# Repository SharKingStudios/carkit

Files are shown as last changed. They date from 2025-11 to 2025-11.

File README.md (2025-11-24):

<p align="center">
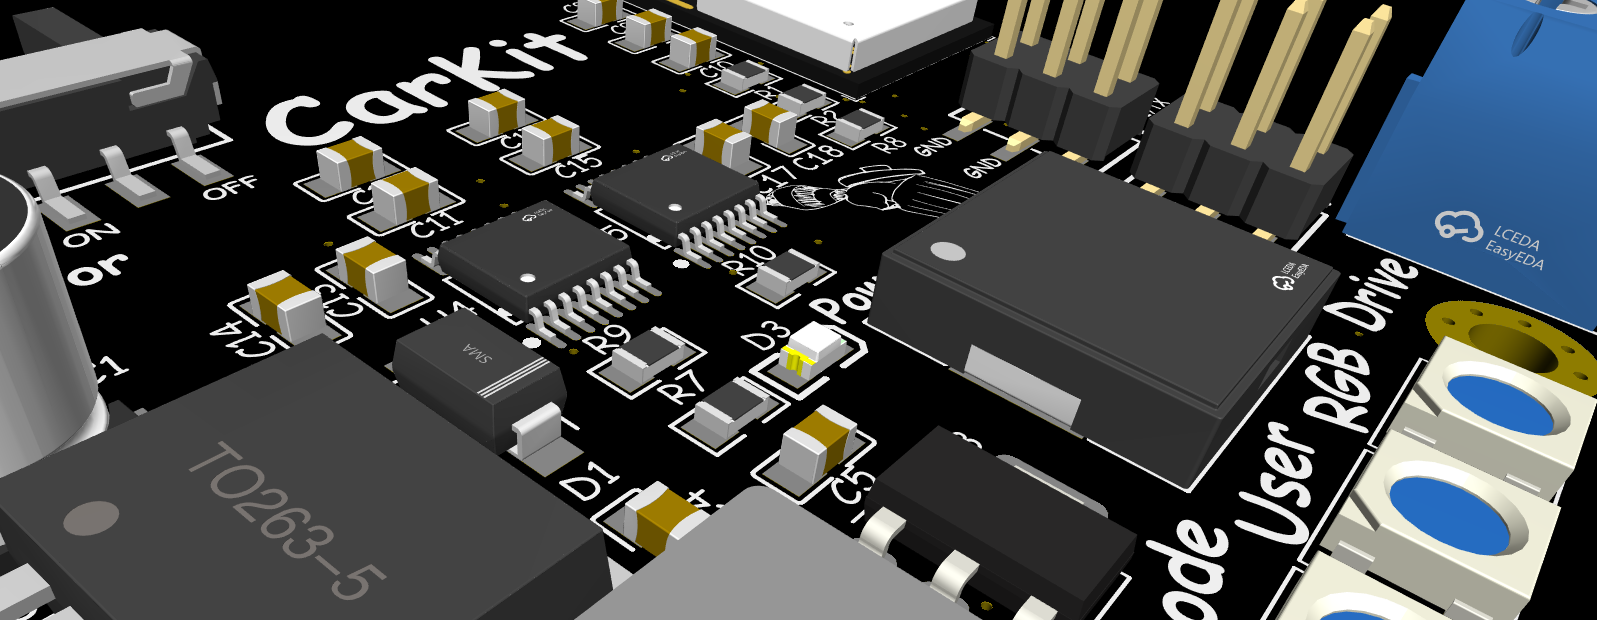
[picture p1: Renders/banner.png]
Banner
  
</p>

# CarKit – Because Your RC Car Needs a Brain  

### A Swiss-Army-Knife Control Board for DIY RC Chaos™  

*(You bring the chassis. It brings the brains.)*  

---

## Renders
*Visuals because everyone loves eye candy.*

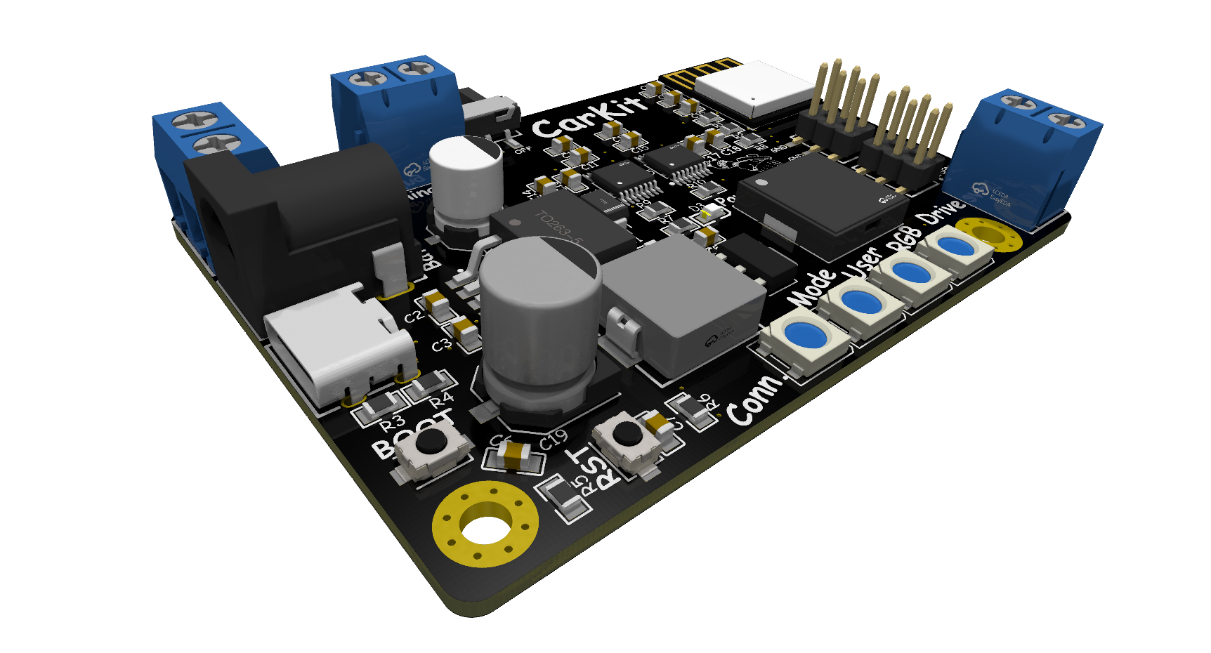
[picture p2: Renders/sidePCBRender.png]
Side PCB Render

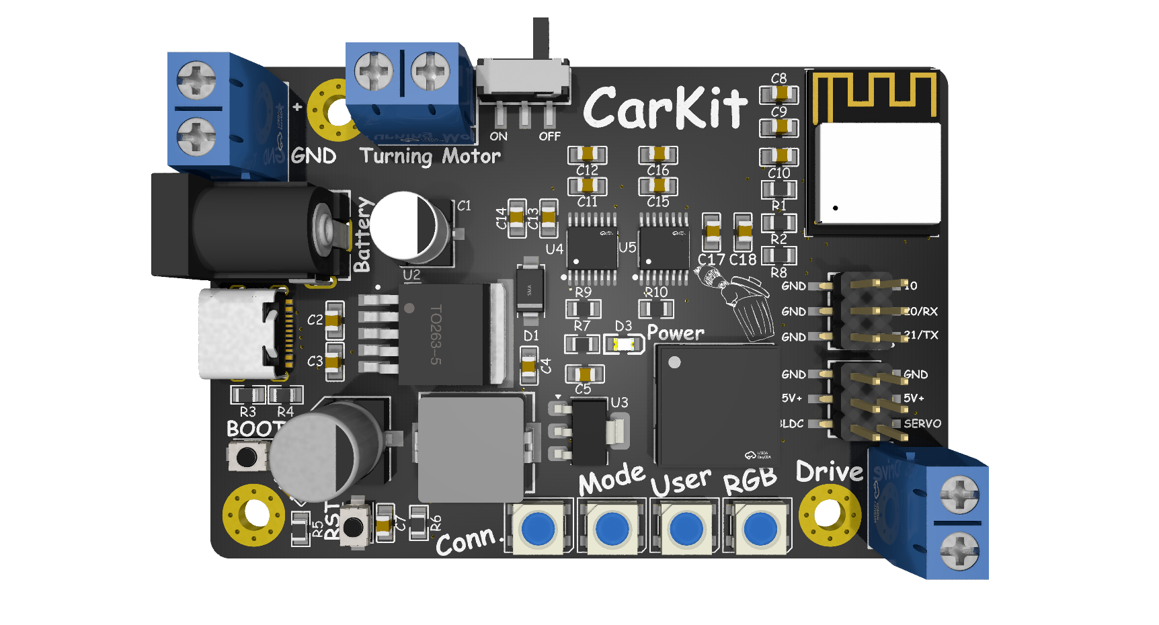
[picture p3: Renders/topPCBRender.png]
Top PCB Render

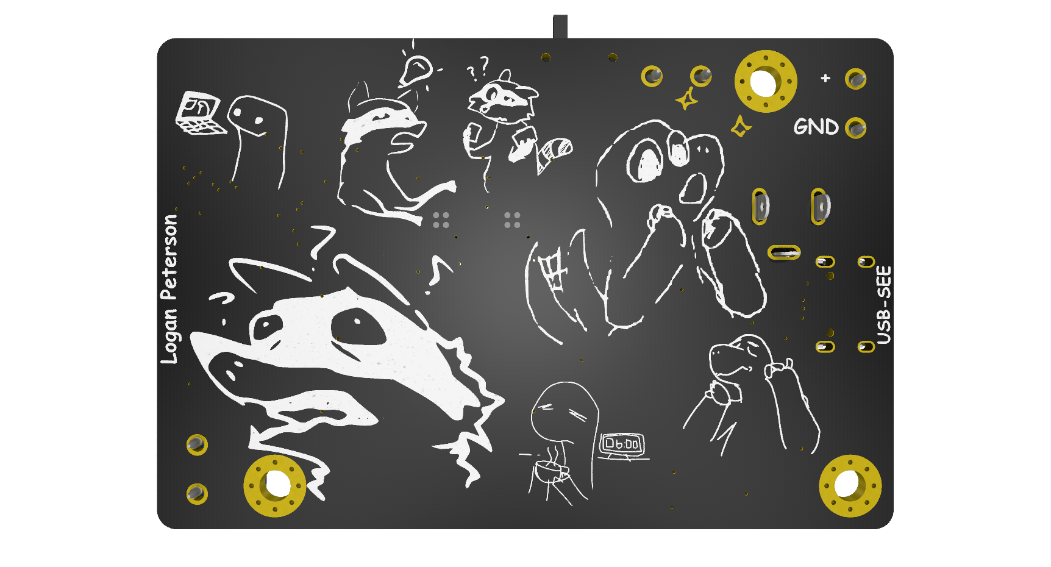
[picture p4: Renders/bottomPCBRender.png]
Bottom PCB Render

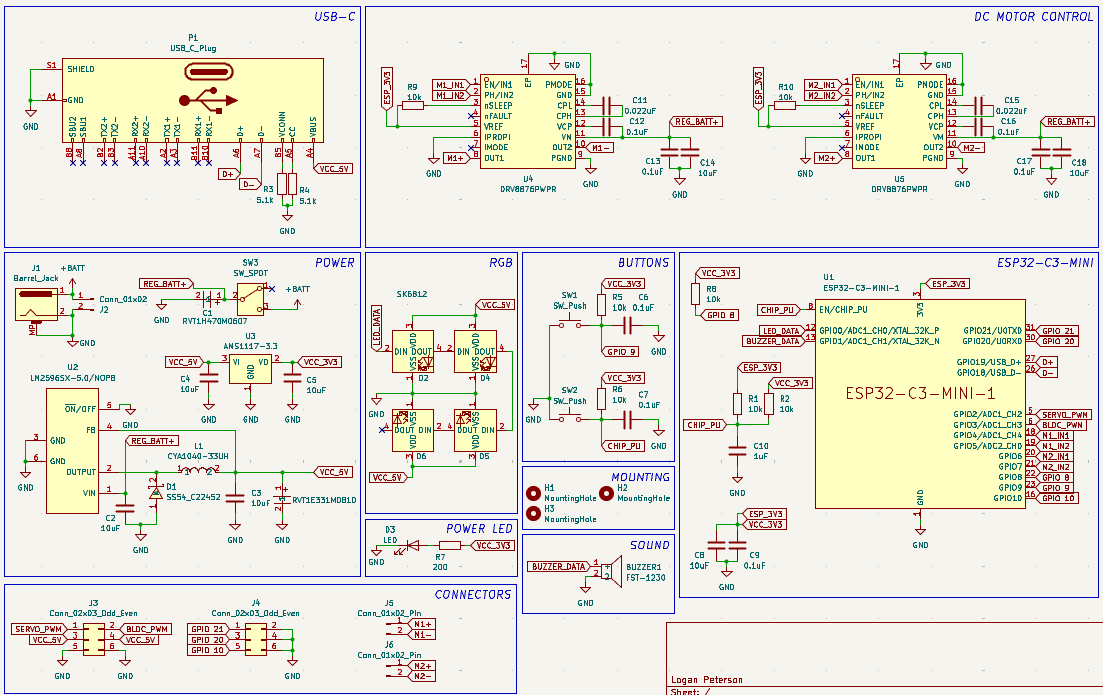
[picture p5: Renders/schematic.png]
Schematic Picture

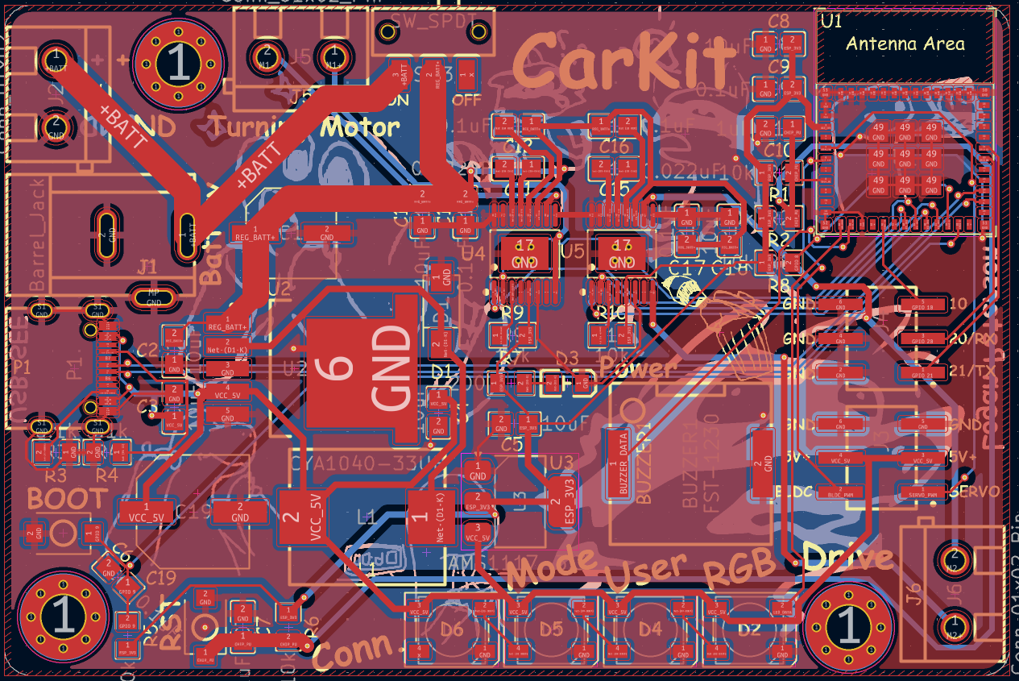
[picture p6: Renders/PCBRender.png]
Routing Glamour Shot


---

## BOM
All the silicon, blinkenlights, and screw-down bits live **[here](/BOM.csv)**.

**Main characters:**
- **MCU:** ESP32-C3-WROOM-02
- **Motor Driver:** DRV8876 dual DC motor driver
- **5 V Regulator:** LM2596SX-5.0 buck converter
- **3.3 V Regulator:** AMS1117-3.3 LDO
- **RGB LEDs:** SK6812 addressable LEDs (x4)
- **Power LED:** XL-2012UVA
- **Inputs:** USB-C, Barrel jack, and screw terminal power
- **Connectors:** KF301 5.0 mm terminal blocks + 2×3 SMT headers  
- **Misc:** Buttons, buzzer, pull-ups, decoupling caps, and the usual supporting cast  

(See `BOM.md` for the full part list, values, and LCSC links.)

---

## What is this?

This is a **do-it-all RC control board** built around an **ESP32-C3**, designed to handle basically everything you might want on a DIY RC car:

- **2 DC motors with PWM** (think: **drive** + **steering/turning**)
- **1 BLDC motor output** (via external ESC)
- **1 servo motor output**
- **Bluetooth gamepad support** (so you can use almost any Bluetooth controller)
- **Multiple power input options** (USB-C, barrel jack, or raw battery via screw terminals)
- **4 RGB status LEDs** for connection, mode, and “because RGB”  
- **On-board buzzer** for beeps, alerts, and dramatic startup tones

It’s meant to be the **drop-in brain** for “I duct-taped this together but now I want it to drive nicely” RC builds.

---

## Features

### Motor Control
- **2× DC motor channels**
  - PWM control for speed
  - Direction control via DRV8876
  - Great for **drive + steering** or **tank drive*** setups
- **1× BLDC channel (signal)**
  - Standard PWM output to an external ESC
- **1× Servo output**
  - For steering, camera gimbals, or cursed animatronics
 
<sub>*While the board supports tank drive it wasn't built for it.</sub>

### Power Options
Because every DIY RC build uses a *different* battery, obviously.

- **USB-C (5 V)**
  - For bench testing, firmware dev, and flexing modern ports
- **Barrel jack**
  - Perfect for **9 V batteries** or standard DC wall adapters
- **Screw terminals**
  - Bring your own LiPo / battery pack
- **On-board power handling:**
  - **LM2596SX-5.0** buck converts input to 5 V
  - **AMS1117-3.3** steps 5 V down to 3.3 V for the ESP32-C3
  - Bulk and decoupling caps sprinkled everywhere to keep noise and brownouts away
  
*(Dont feed the board anything over 36V, I would recommend staying under 24V)*

### LEDs & Buttons
- **4× SK6812 RGB LEDs**
  - Can show:
    - **Connection status** (paired / searching / sad)
    - **Board mode** (e.g. normal, config, debug)
    - **User-defined patterns** (rainbow, brake lights, underglow, whatever)
- **1× Power LED**
  - Because sometimes you just need “is this thing on?”
- **Tactile buttons**
  - For reset and boot functions (programming)

### Connectivity & IO
- **ESP32-C3 MCU**
  - **Wi-Fi + Bluetooth LE**
  - Extra GPIOs broken out via **2×3 SMT headers** for expansion
- **Screw terminal outputs**
  - For motors, power, and other “don’t-come-loose” connections

---

## Motor Channels Overview  

| Channel | Type | Typical Use | Notes |
|---|---|---|---|
| M1 | DC Motor | Main Drive | PWM + DIR via DRV8876 |
| M2 | DC Motor | Turning / Steering | PWM + DIR via DRV8876 |
| BLDC OUT | PWM Signal  | Brushless ESC Input | External ESC drives the BLDC motor |
| SERVO OUT | Servo PWM | Steering / Gimbal / Etc. | Standard RC-style servo signal |

---

## How It Works

At a high level:

1. **You power the board** via USB-C, barrel jack, or screw terminals.  
2. The **LM2596** generates a solid 5 V rail, and the **AMS1117** creates the 3.3 V rail for the ESP32-C3.  
3. The **ESP32-C3** runs your firmware:
   - Reads input from a **Bluetooth controller**
   - Outputs PWM and direction signals to the **DRV8876** for the DC motors  
   - Generates PWM for the **BLDC ESC** and **servo**  
   - Drives the **SK6812 RGB LEDs** and **buzzer** to show status and vibes  

All the “annoying parts” (power, drivers, IO protection, connectors, etc.) are on the PCB, so you can focus on mechanical design.

---

## Using a Bluetooth Controller

The exact firmware and controller mapping is up to you and some basic stuff is included, but the general idea is:

1. Flash your ESP32-C3 firmware that:
   - Pairs with a **Bluetooth gamepad / controller**
   - Maps sticks/triggers/buttons to motor speeds and steering
2. On startup, the **RGB LEDs** can:
   - Pulse / chase while waiting for a controller  
   - Turn solid once connected  
3. Drive your RC car like a normal RC car, but with way more flexibility and hackability.

*(You can map “A” to beep the buzzer. You absolutely should.)*

---

## RGB LEDs  

Because a control board without RGB is just morally wrong.

Possible roles for the **4 SK6812 LEDs**:

- **LED 1 – Connection status (Bluetooth)**  
- **LED 2 – Mode indicator (normal / config / debug)**  
- **LED 3-4 – User bling (animations, underglow, warnings, etc.)**

Or ignore all that and just run full rainbow vomit. No judgment.

---

## Why?  

This board exists for that moment when you’ve got:

- An RC chassis
- Some motors
- A pile of batteries
- And zero desire to reinvent **“basic motor control + power + Bluetooth”** *again*

It’s meant to be the **one board** that handles:
- Motors
- Power
- Input
- Feedback

…so you can just design something cool and let this handle the boring electronics.

---

## Contribute  

Have ideas? Want a new connector, mode, sample firmware, or just want to roast my layout?

- Open an **issue**
- Submit a **PR**
- Or just yell at me on GitHub with suggestions

---

## Disclaimer  

This project is open-source, powered by **vibes**, and tested mostly on my own questionable hardware.  

If you:
- Overvolt it  
- Reverse the battery  
- Strap it to a rocket  
- Or send 48 V into something that wanted 5 V  

…and it smokes, explodes, or develops sentience, that’s **entirely on you.**

Happy hacking!

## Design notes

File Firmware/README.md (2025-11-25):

<p align="center">
  Banner
</p>

# CarKit Firmware  

### ESP32-C3 firmware for the CarKit RC control board  

---

## What is this?

This folder contains the **firmware** for the CarKit board – an all-in-one **ESP32-C3-WROOM-02-H4**–based controller for RC cars.

The firmware handles:

- **Bluetooth gamepad input** (via Bluepad32)
- **Drive + steering DC motors** (DRV8876 drivers)
- Optional **servo steering** and **BLDC/ESC** output
- **4× RGB LEDs** for status/mode/feedback
- An on-board **buzzer** for power-on tones, connect chirps, and a horn
- Optional **Wi-Fi debug web page** to configure and persist settings (NVS)

If the PCB is the body, this is the nervous system.

---

## Features Overview

- **Bluetooth Controller Support**
  - Uses **Bluepad32** to support Xbox-style and other BLE gamepads.
  - Reads triggers, sticks, and buttons for driving and mode control.

- **Two Drive Modes**
  - **Car Mode** (default)  
    - Throttle from **triggers** (forward/reverse).
    - Steering from **left stick X**.
  - **Tank Mode**  
    - Left/Right “tracks” from **left stick Y** and **right stick Y**.
    - Mapping of **which motor driver is left/right** is configurable.

- **Motor Outputs**
  - **U4 DRV8876** → Steering DC motor
  - **U5 DRV8876** → Drive DC motor
  - Each with:
    - **PWM speed control**
    - **Direction control**
    - Optional **invert flags** in firmware so you can fix direction without rewiring.

- **Servo + BLDC Support (Optional)**
  - **Servo output** on `GPIO2` (e.g. steering servo).
  - **BLDC/ESC signal** on `GPIO3` (for brushless motor via external ESC).
  - Both can be enabled/disabled via constants and web UI.

- **Addressable RGB LEDs (4× SD6812/SK6812)**
  - Provide:
    - Connection status
    - Drive mode indication
    - Live feedback for throttle and steering
    - Simple startup / pairing animations

- **Buzzer (FST-1230 on GPIO 1)**
  - Power-on jingle
  - “Controller connected” chirp
  - Horn while a button is held (default: **A** button)

- **Debug Web UI (Optional)**
  - ESP32-C3 hosts a small Wi-Fi AP and web page.
  - Lets you tune and save config (NVS) without recompiling.

---

## Pin Mapping (Firmware View)

| Function | GPIO | Notes |
|---|---|---|
| RGB LED Data (4× SD6812) | 0 | LED chain input |
| Buzzer (FST-1230) | 1 | PWM-driven, used for jingles + horn |
| Servo Signal | 2 | Optional steering / general RC servo |
| BLDC / ESC Signal | 3 | Optional ESC throttle signal |
| Steering DC EN (U4 DRV8876)  | 4 | PWM (EN) for steering DC motor |
| Steering DC PH (U4 DRV8876)  | 5 | Direction for steering motor |
| Drive DC EN (U5 DRV8876) | 6 | PWM (EN) for drive DC motor |
| Drive DC PH (U5 DRV8876) | 7 | Direction for drive motor |
| USB D- / D+ | 18/19| USB interface (depends on your board layout) |
| Extra GPIOs | 10/20/21 | Broken out, unused by firmware internally |

If you make a board revision and it changes any of these, update the pin constants at the top of `CarKit_Firmware.ino`.

---

## LED Layout (Firmware Roles)

There are **4 addressable LEDs** chained on `GPIO0`. The firmware uses them as:

| Index | Role | Description |
|---|---|---|
| 0 | User LED 1 | Throttle visualization (forward/reverse intensity) |
| 1 | User LED 2 | Steering visualization (left/right intensity) |
| 2 | Mode LED | Drive mode (Car vs Tank) |
| 3 | Status LED | Bluetooth status (pairing vs connected) |

Animations include:

- Boot “wipe” animation on startup.
- Pulsing status while waiting for a controller.
- Solid connection color when a controller is paired.

---

## Gamepad Mapping

### Car Mode (Default)

- **Throttle**
  - **Right trigger** → forward.
  - **Left trigger** → reverse.
  - Firmware combines them into a single value:  
    `drive = forward_trigger - reverse_trigger`.

- **Steering**
  - **Left stick X** (left/right).

- **Horn**
  - Default: **A button**.
  - Press & hold = horn tone (buzzer on GPIO 1).

- **Drive Mode Toggle**
  - Default: **Y button**.
  - Toggles between **Car Mode** and **Tank Mode**.
  - The last used mode is stored in NVS and restored on boot.

### Tank Mode

- **Left motor**  = **Left stick Y** (up/down).
- **Right motor** = **Right stick Y** (up/down).

Which DRV8876 (U4 vs U5) is considered “left” is configurable (no need to swap wires on the board).

---

## Configuration & Constants

Most behavior is controlled by constants at the top of `CarKit_Firmware.ino`:

### Motor Direction

```cpp
const bool DEFAULT_REVERSE_STEERING_DC = false;  // reverse U4 sense
const bool DEFAULT_REVERSE_DRIVE_DC    = false;  // reverse U5 sense
```
Flip these to `true` if a motor spins “backwards”.

### Feature Toggles
```cpp
const bool DEFAULT_ENABLE_BLDC_OUTPUT  = false;  // ESC on GPIO3
const bool DEFAULT_ENABLE_SERVO_OUTPUT = true;   // servo on GPIO2
const bool DEFAULT_TANK_LEFT_IS_U4     = true;   // true: U4 = left, false: U5 = left
```
Use these to enable/disable outputs and tank drive mapping.

### Servo Settings
```cpp
const int DEFAULT_SERVO_CENTER_US      = 1500;   // servo center pulse width (microseconds)
const int DEFAULT_SERVO_MIN_US         = 1000;   // min pulse (microseconds)
const int DEFAULT_SERVO_MAX_US         = 2000;   // max pulse (microseconds)
```
Adjust `DEFAULT_SERVO_CENTER_US` if your steering servo sits slightly off center.

### Input / Mode Defaults
```cpp
const HornButton DEFAULT_HORN_BUTTON   = HORN_BTN_A;       // A/B/X/Y
const DriveMode  DEFAULT_DRIVE_MODE    = DRIVE_MODE_CAR;   // CAR or TANK
```
These define the default horn button and drive mode on first boot.

---

## Persistent Settings (NVS)

The firmware uses the ESP32’s Preferences (NVS) to store configuration at runtime:
- Reverse flags (steering/drive)
- Servo enable / BLDC enable
- Tank mapping (which side is U4)
- Servo center trim (µs)
- Horn button choice
- Default drive mode

On first boot, firmware uses the compile-time defaults.
After you change settings via the web UI (or code), they are saved to NVS and override defaults on subsequent boots.

If your configuration gets messy, you can clear NVS (e.g. via another sketch or ESP32 erase tools) to go back to the original defaults.

---

## Debug Web UI

> Optional but very handy while tuning

If `ENABLE_DEBUG_WEBUI` is set to `1` in `CarKit_Firmware.ino`, the ESP32-C3:
 - Starts a Wi-Fi access point: 
   - SSID: CarKit-Debug
   - Password: carkit123 (change in code if desired)
 - Hosts a small config site at:
   - `http://192.168.4.1/`
 - Lets you edit and save:
   - Reverse steering / drive
   - Enable/disable servo output and BLDC output
   - Tank mapping (U4 vs U5 as left)
   - Servo center (microseconds)
   - Horn button (A/B/X/Y)
   - Default drive mode (Car / Tank)

When you click Save:
 - Values are written into NVS.
 - Some changes apply immediately; all are loaded on next boot.

To remove the web UI set:
```cpp
#define ENABLE_DEBUG_WEBUI 0
```
near the top of the file and recompile.

---

## Safety / Failsafes

 - The firmware uses a simple idle timeout:
   - If no controller updates arrive for a short period, throttle and steering commands are forced to zero to stop the motors.

 - On controller disconnect:
   - Internally commanded speeds are set to zero.
   - The status LED reverts to “searching/pairing” pattern.

You should still test carefully and use reasonable supply voltages.

---

## Build & Flash Instructions

### 1. Toolchain Setup

You’ll need:

- **Arduino IDE** (recommended) or **PlatformIO**
- The **Bluepad32 ESP32 core** installed (board package that provides `esp32_bluepad32` boards)

For Arduino IDE, follow the Bluepad32 docs to add their ESP32 board URL, then install the `esp32_bluepad32` package.

---

### 2. Board Selection (Arduino IDE)

In **Tools → Board**, select:

> `esp32_bluepad32 → LOLIN C3 Mini`

This matches the **ESP32-C3-WROOM-02-H4** module closely enough for flash size, CPU, and Bluetooth LE.

---

### 3. Required Libraries

Install these from **Tools → Manage Libraries…**:

- **Adafruit NeoPixel**

These are included with the ESP32 / Bluepad32 cores and don’t usually need separate installation:

- **Bluepad32**
- **Preferences**
- **WiFi**
- **WebServer**

If the IDE complains about missing headers, double-check that:
- The correct board core (`esp32_bluepad32`) is selected, and  
- The libraries above are installed/enabled.

---

### 4. Uploading the Firmware

1. Open `CarKit_Firmware.ino` in **Arduino IDE**.
2. Under **Tools**:
   - Set **Board** to `LOLIN C3 Mini (esp32_bluepad32)`.
   - Set the correct **Port** for your CarKit board (USB-C serial).
3. Click **Upload**.

If your board requires a bootloader sequence:

- Hold **BOOT** (if present), press and release **RESET**, then release **BOOT**.
- Try uploading again.

On a successful upload you should see:

- Buzzer plays the **power-on jingle**.
- The RGB LEDs do a **boot animation**.
- The status LED goes into a “waiting for controller” pattern until a gamepad connects.

---

## Resetting Configuration

If you’ve played with settings and want to go back to firmware defaults:

 - Erase the ESP32-C3’s NVS partition (e.g. using esptool.py or a dedicated “erase” sketch)

On next boot, the firmware will use the compile-time defaults again.

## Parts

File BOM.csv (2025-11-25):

Value | Qty | Price Ea. | Price total (MOQ) | LCSC link
ESP32-C3-WROOM-02-H4 (MCU) | 1 | 3.2978 | 3.30 | https://www.lcsc.com/product-detail/C2944070.html
DRV8876PWPR (Dual DC Motor Driver) | 2 | 0.6088 | 1.22 | https://www.lcsc.com/product-detail/C575551.html
LM2596SX-5.0/NOPB (5V buck) | 1 | 0.8804 | 0.88 | https://www.lcsc.com/product-detail/C10002.html
AMS1117-3.3V (3.3V LDO) | 1 | 0.0342 | 0.36 | https://www.lcsc.com/product-detail/C5120765.html
FST-1230 Buzzer | 1 | 0.4612 | 0.46 | https://www.lcsc.com/product-detail/C391037.html
47uF 50V electrolytic (RVT1H470M0607) | 1 | 0.029 | 0.61 | https://www.lcsc.com/product-detail/C72523.html
10uF 25V X5R 0805 (CL21A106KAYNNNE) | 7 | 0.0101 | 0.20 | https://www.lcsc.com/product-detail/C15850.html
0.1uF 50V X7R 0805 (CL21B104KBCNNNC) | 7 | 0.0060 | 0.30 | https://www.lcsc.com/product-detail/C1711.html
1uF 50V X7R 0805 (CL21B105KBFNNNE) | 1 | 0.0092 | 0.18 | https://www.lcsc.com/product-detail/C28323.html
0.022uF 50V X7R 0805 (TCC0805X7R223K500DT) | 2 | 0.0058 | 0.58 | https://www.lcsc.com/product-detail/C282752.html
330uF bulk cap (RVT1E331M0810) | 1 | 0.0540 | 0.54 | https://www.lcsc.com/product-detail/C335985.html
SS54 Schottky diode | 1 | 0.0450 | 0.45 | https://www.lcsc.com/product-detail/C22452.html
SK6812 RGB LED | 4 | 0.0850 | 0.43 | https://www.lcsc.com/product-detail/C5378720.html
XL-2012UVA Power LED | 1 | 0.0130 | 0.65 | https://www.lcsc.com/product-detail/C7371915.html
10k 0805 resistor | 7 | 0.0018 | 0.18 | https://www.lcsc.com/product-detail/C17414.html
5.1k 0805 resistor | 2 | 0.0019 | 0.19 | https://www.lcsc.com/product-detail/C27834.html
200R 0805 resistor | 1 | 0.0013 | 0.14 | https://www.lcsc.com/product-detail/C2933534.html
TS-1088-AR02016 Tactile Switch | 2 | 0.0417 | 0.42 | https://www.lcsc.com/product-detail/C720477.html
KF301-5.0-2P Terminal Block | 3 | 0.0867 | 0.43 | https://www.lcsc.com/product-detail/C474881.html
DC-005-A200 Barrel Jack | 1 | 0.1161 | 0.58 | https://www.lcsc.com/product-detail/C720557.html
USB-TYPE-C-018 Receptacle | 1 | 0.0484 | 0.48 | https://www.lcsc.com/product-detail/C2927038.html
PZ2.54-2*40-SMT (to cut) | 1 | 0.4828 | 0.48 | https://www.lcsc.com/product-detail/C5378174.html
CYA1040-33UH Inductor | 1 | 0.3500 | 1.60 | https://www.lcsc.com/product-detail/C6364680.html
MST-12D18G4 SPDT Slide Switch | 1 | 0.0380 | 0.38 | https://www.lcsc.com/product-detail/C49023767.html
LCSC parts total (FOR 10 BOARDS) |  |  | 70.09
LCSC order shipping |  |  | 15.47 | https://www.lcsc.com/
JLCPCB Fabrication | 10 |  | 5.00 | https://jlcpcb.com/
JLCPCB Stencil | 1 |  | 7.00 | https://jlcpcb.com/
JLCPCB Shipping |  |  | 14.15 | https://jlcpcb.com/
Total |  |  | 112.06
Top Up for extra PCBs order |  |  | 5.00 | (Extra production cost + shipping for +5 PCBs)
Top Up for extra parts |  |  | 55.56 | (84.71 - 29.15 LCSC parts total for 10 boards)
Total Top Up |  |  | 60.56

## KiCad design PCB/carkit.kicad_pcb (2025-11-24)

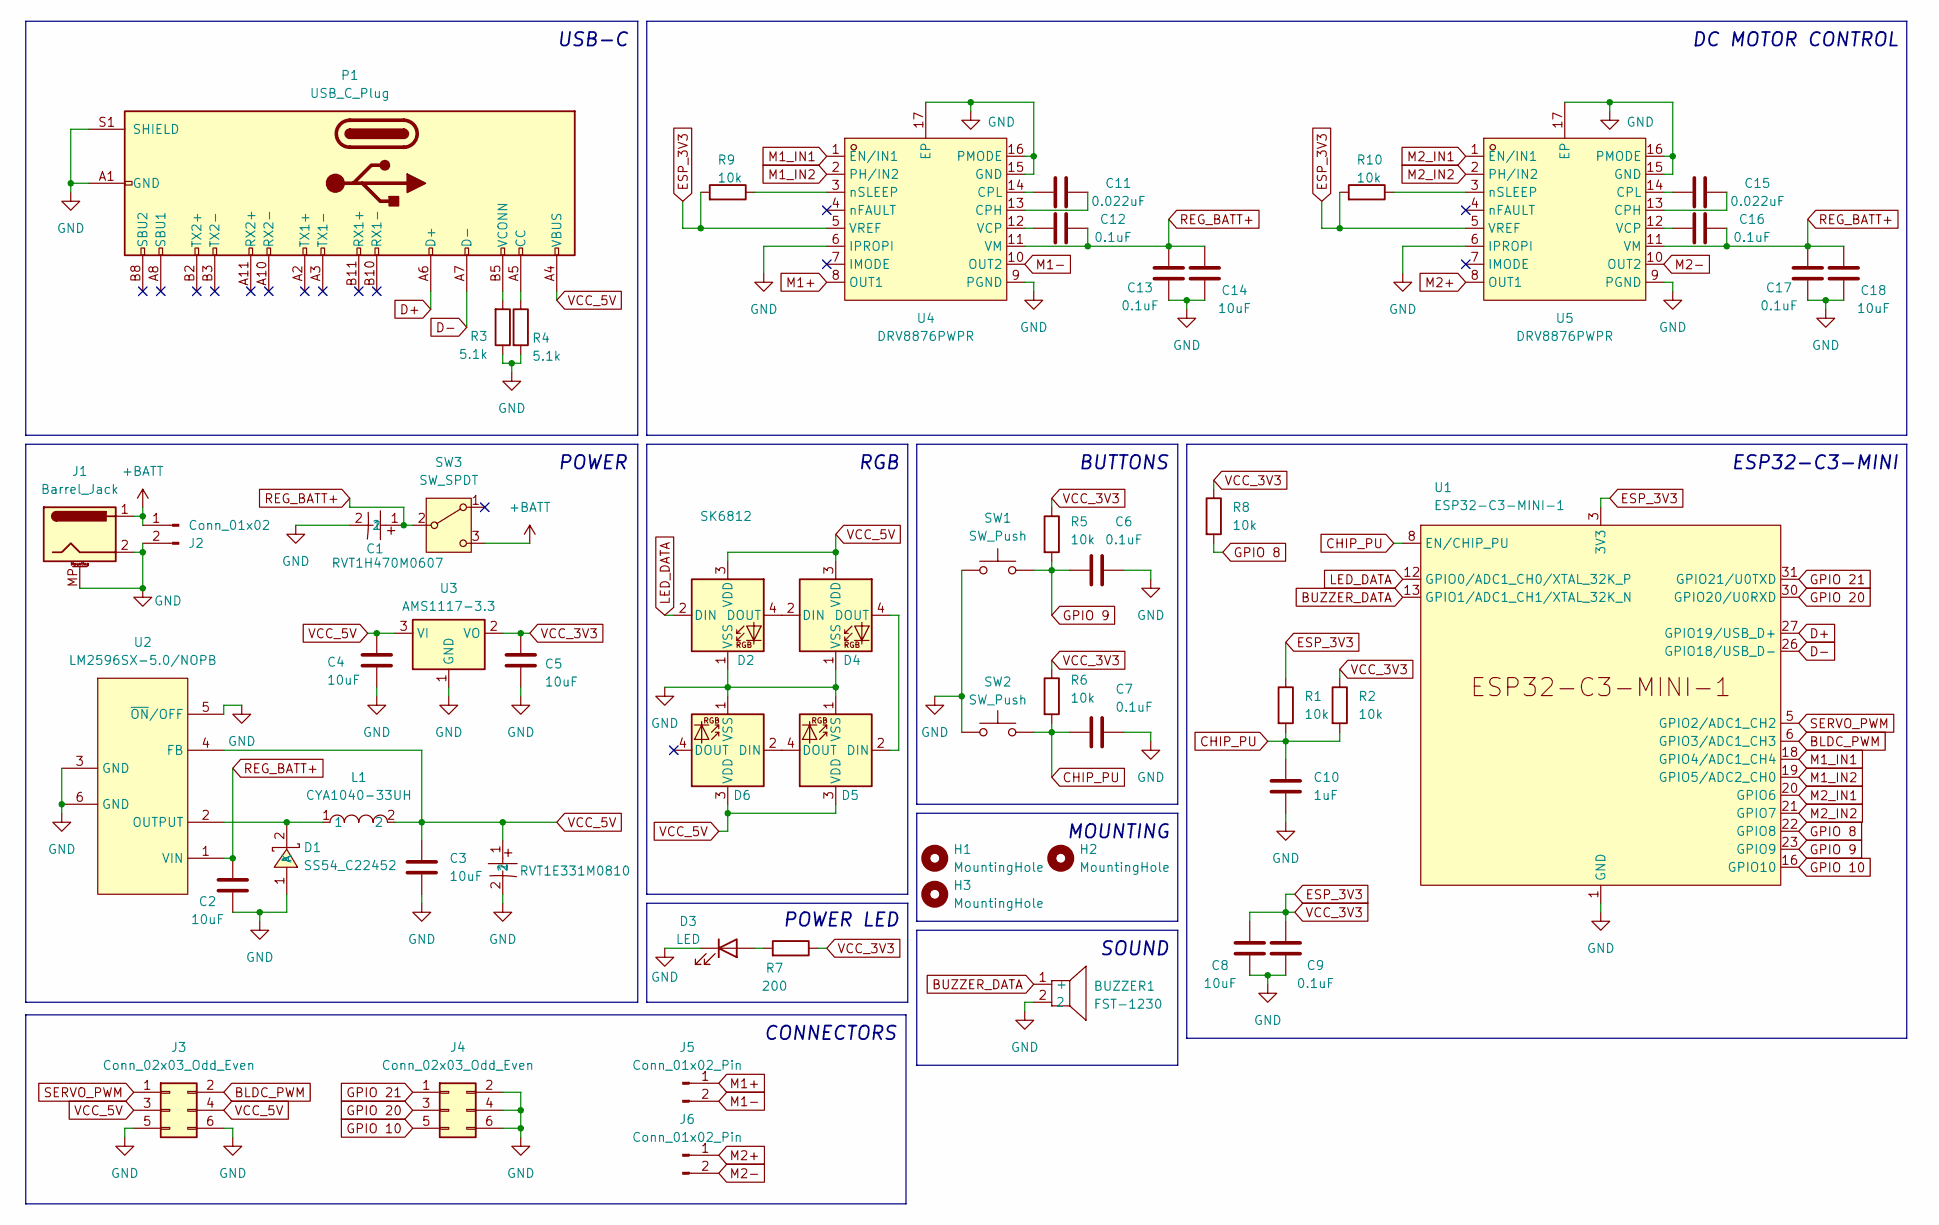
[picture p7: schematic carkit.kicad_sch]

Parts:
BUZZER1: FST-1230; BUZ-SMD_L12.0-W12.0_FUET-1230; LCSC Part C391037
C1: RVT1H470M0607; CAP-SMD_BD6.3-L6.6-W6.6-LS7.6-FD; LCSC Part C72523
C2, C3, C4, C5, C8, C14, C18: 10uF; C0805
C6, C7, C9, C12, C13, C16, C17: 0.1uF; C0805
C10: 1uF; C0805
C11, C15: 0.022uF; C0805
C19: RVT1E331M0810; CAP-SMD_BD8.0-L8.3-W8.3-LS9.3-FD-1; LCSC Part C335985
D1: SS54_C22452; SMA_L4.4-W2.8-LS5.4-R-RD; LCSC Part C22452
D2, D4, D5, D6: SK6812; LED_SK6812_PLCC4_5.0x5.0mm_P3.2mm
D3: LED; LED0805-RD
H1, H2, H3: MountingHole; MountingHole_3.2mm_M3_Pad_Via
J1: Barrel_Jack; DC-IN-TH_DC-005-A200
J2: Conn_01x02; CONN-TH_P5.00_KF301-5.0-2P
J3, J4: Conn_02x03_Odd_Even; HDR-SMD_6P-P2.54-V
J5, J6: Conn_01x02_Pin; CONN-TH_P5.00_KF301-5.0-2P
L1: CYA1040-33UH; IND-SMD_L11.6-W10.1; LCSC Part C6364680
P1: USB_C_Plug; USB-C_SMD-TYPE-C-31-M-12
R1, R2, R5, R6, R8, R9, R10: 10k; R0805
R3, R4: 5.1k; R0805
R7: 200; R0805
SW1, SW2: SW_Push; SW-SMD_L3.9-W3.0-P4.45
SW3: SW_SPDT; SW-SMD_MST-12D18G4-SPDT-SLIDE-SWITCH
U1: ESP32-C3-MINI-1
U2: LM2596SX-5.0/NOPB; TO-263-5_L10.2-W8.9-P1.70-TL; LCSC Part C10002
U3: AMS1117-3.3; SOT-223-3_TabPin2
U4, U5: DRV8876PWPR; HTSSOP-16_L5.0-W4.4-P0.65-LS6.4-BL-EP; LCSC Part C575551

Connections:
+BATT: J1.1, J2.1, SW3.3 (C)
BLDC_PWM: J3.2, U1.6 (GPIO3/ADC1_CH3)
BUZZER_DATA: BUZZER1.1 (+), U1.13 (GPIO1/ADC1_CH1/XTAL_32K_N)
CHIP_PU: C7.1, C10.1, R1.2, R2.2, R6.2, SW2.1, U1.8 (EN/CHIP_PU)
D+: P1.A6 (D+), U1.27 (GPIO19/USB_D+)
D-: P1.A7 (D-), U1.26 (GPIO18/USB_D-)
ESP_3V3: C5.1, C8.2, C9.2, R1.1, R2.1, R5.1, R6.1, R7.1, R8.1, R9.2, R10.2, U1.3 (3V3), U3.2 (VO), U4.5 (VREF), U5.5 (VREF)
GND: BUZZER1.2, C1.2, C2.1, C3.2, C4.2, C5.2, C6.2, C7.2, C8.1, C9.1, C10.2, C13.1, C14.1, C17.1, C18.1, C19.2, D1.1 (A), D2.1 (VSS), D3.1 (K), D4.1 (VSS), D5.1 (VSS), D6.1 (VSS), J1.2, J1.MP (MountPin), J2.2, J3.5, J3.6, J4.2, J4.4, J4.6, P1.A1 (GND), P1.A12 (GND), P1.B1 (GND), P1.B12 (GND), P1.S1 (SHIELD), R3.1, R4.2, SW1.2, SW2.2, U1.1 (GND), U1.2 (GND), U1.11 (GND), U1.14 (GND), U1.36 (GND), U1.37 (GND), U1.38 (GND), U1.39 (GND), U1.40 (GND), U1.41 (GND), U1.42 (GND), U1.43 (GND), U1.44 (GND), U1.45 (GND), U1.46 (GND), U1.47 (GND), U1.48 (GND), U1.49 (GND), U1.50 (GND), U1.51 (GND), U1.52 (GND), U1.53 (GND), U2.3 (GND), U2.5 (~ON/OFF), U2.6 (GND), U3.1 (GND), U4.6 (IPROPI), U4.9 (PGND), U4.15 (GND), U4.16 (PMODE), U4.17 (EP), U5.6 (IPROPI), U5.9 (PGND), U5.15 (GND), U5.16 (PMODE), U5.17 (EP)
GPIO 8: R8.2, U1.22 (GPIO8)
GPIO 9: C6.1, R5.2, SW1.1, U1.23 (GPIO9)
GPIO 10: J4.5, U1.16 (GPIO10)
GPIO 20: J4.3, U1.30 (GPIO20/U0RXD)
GPIO 21: J4.1, U1.31 (GPIO21/U0TXD)
LED_DATA: D2.2 (DIN), U1.12 (GPIO0/ADC1_CH0/XTAL_32K_P)
M1+: J5.1, U4.8 (OUT1)
M1-: J5.2, U4.10 (OUT2)
M1_IN1: U1.18 (GPIO4/ADC1_CH4), U4.1 (EN/IN1)
M1_IN2: U1.19 (GPIO5/ADC2_CH0), U4.2 (PH/IN2)
M2+: J6.1, U5.8 (OUT1)
M2-: J6.2, U5.10 (OUT2)
M2_IN1: U1.20 (GPIO6), U5.1 (EN/IN1)
M2_IN2: U1.21 (GPIO7), U5.2 (PH/IN2)
unnamed: D1.2 (K), L1.1, U2.2 (OUTPUT)
unnamed: D2.4 (DOUT), D4.2 (DIN)
unnamed: D3.2 (A), R7.2
unnamed: D4.4 (DOUT), D5.2 (DIN)
unnamed: D5.4 (DOUT), D6.2 (DIN)
unnamed: P1.A5 (CC), R4.1
unnamed: P1.B5 (VCONN), R3.2
unnamed: C11.1, U4.13 (CPH)
unnamed: C11.2, U4.14 (CPL)
unnamed: C12.2, U4.12 (VCP)
unnamed: R9.1, U4.3 (nSLEEP)
unnamed: C15.1, U5.13 (CPH)
unnamed: C15.2, U5.14 (CPL)
unnamed: C16.2, U5.12 (VCP)
unnamed: R10.1, U5.3 (nSLEEP)
REG_BATT+: C1.1, C2.2, C12.1, C13.2, C14.2, C16.1, C17.2, C18.2, SW3.2 (B), U2.1 (VIN), U4.11 (VM), U5.11 (VM)
SERVO_PWM: J3.1, U1.5 (GPIO2/ADC1_CH2)
VCC_5V: C3.1, C4.1, C19.1, D2.3 (VDD), D4.3 (VDD), D5.3 (VDD), D6.3 (VDD), J3.3, J3.4, L1.2, P1.A4 (VBUS), P1.A9 (VBUS), P1.B4 (VBUS), P1.B9 (VBUS), U2.4 (FB), U3.3 (VI)

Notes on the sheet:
MOUNTING
POWER
CONNECTORS
BUTTONS
USB-C
ESP32-C3-MINI
POWER LED
RGB
DC MOTOR CONTROL
SOUND

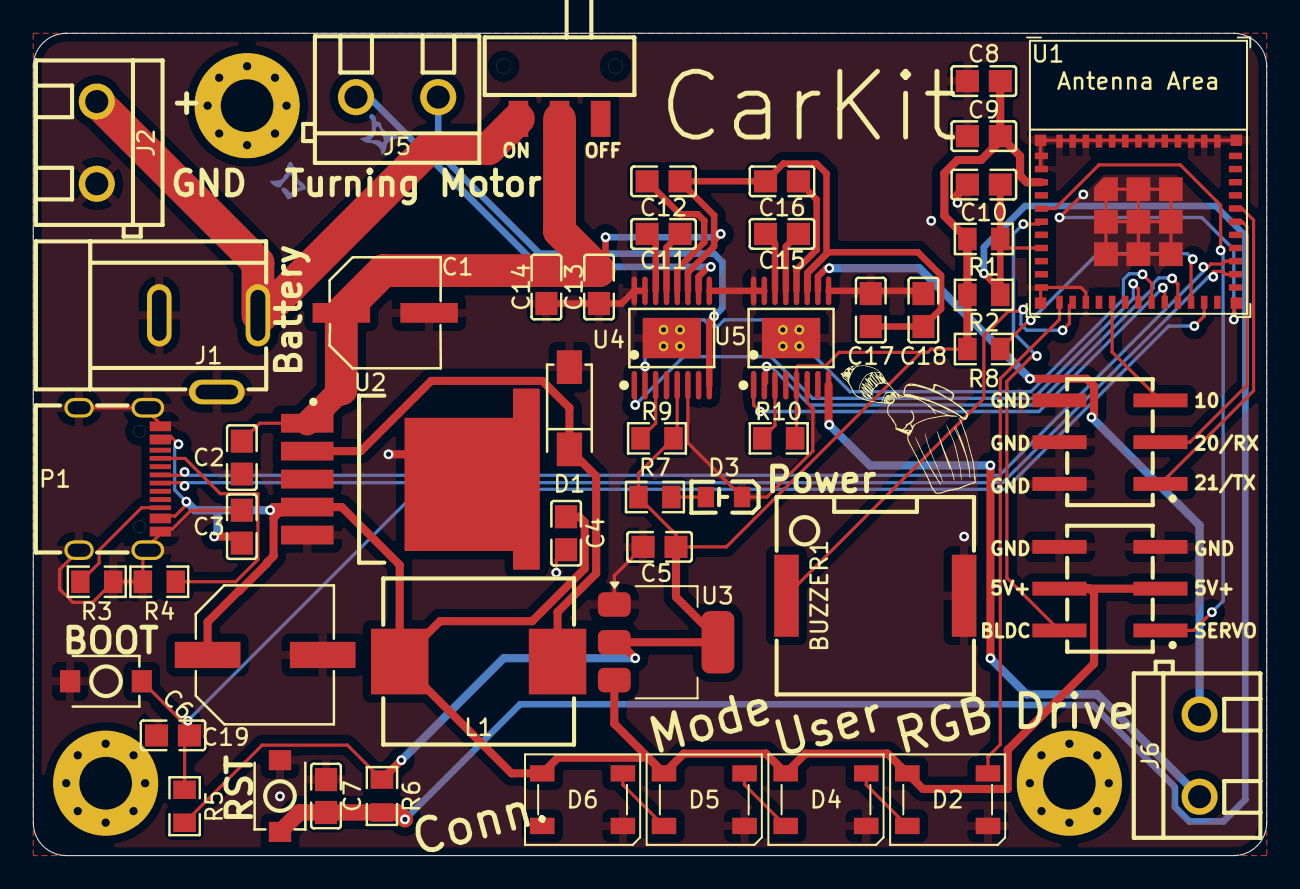
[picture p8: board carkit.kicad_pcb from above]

Board: 2 copper layers, 75.0 x 50.0 mm, 55 parts (0 on the bottom side), 40 nets.

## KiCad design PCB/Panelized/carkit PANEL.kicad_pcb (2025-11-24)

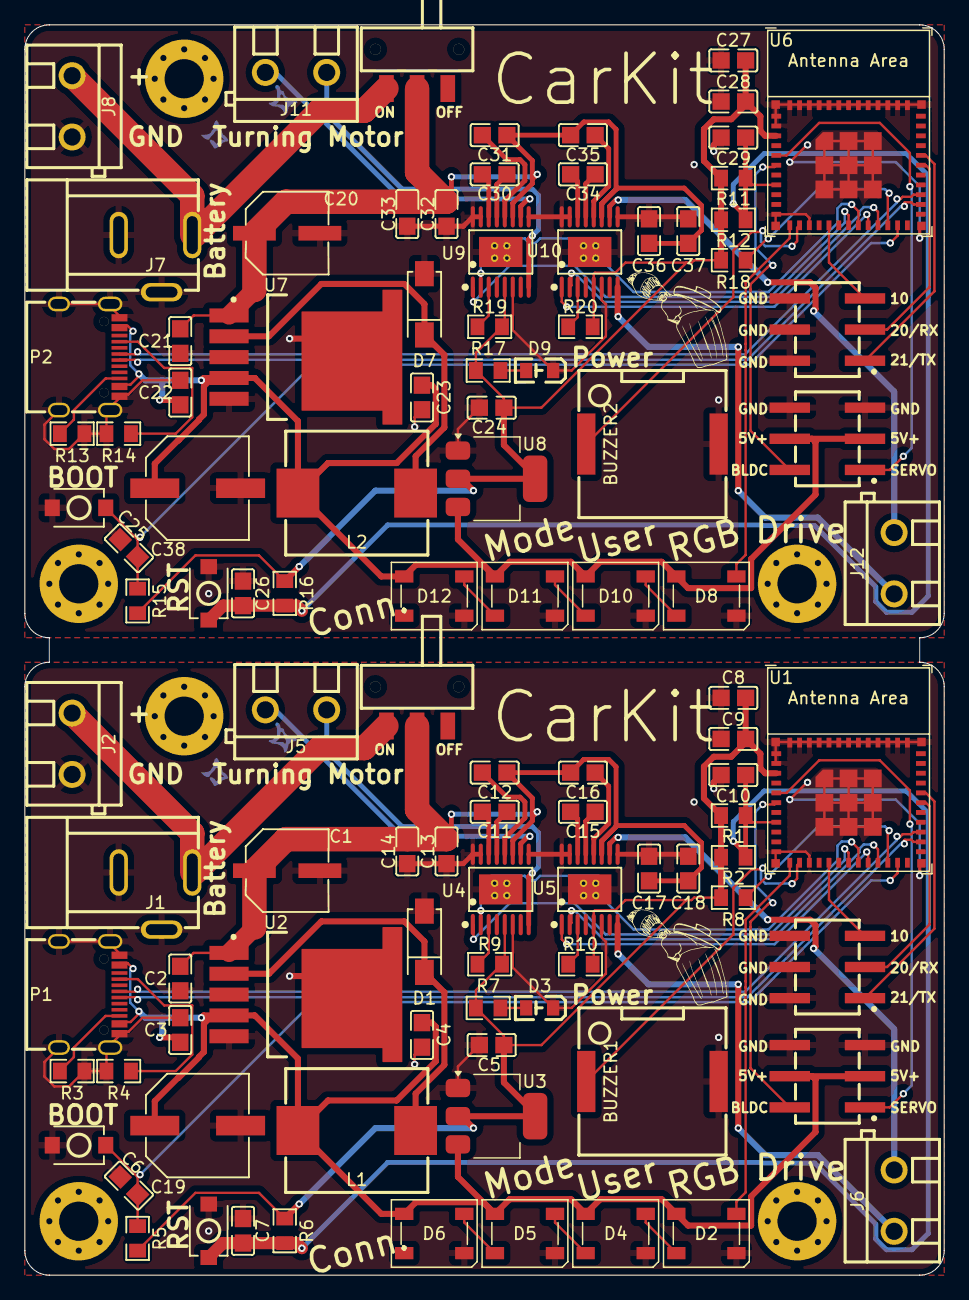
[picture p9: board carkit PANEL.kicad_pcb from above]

Board: 2 copper layers, 75.0 x 102.0 mm, 110 parts (0 on the bottom side), 40 nets.

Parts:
BUZZER1, BUZZER2: FST-1230; BUZ-SMD_L12.0-W12.0_FUET-1230
C1, C20: RVT1H470M0607; CAP-SMD_BD6.3-L6.6-W6.6-LS7.6-FD
C2, C3, C4, C5, C8, C14, C18, C21, C22, C23, C24, C27, C33, C37: 10uF; C0805
C6, C7, C9, C12, C13, C16, C17, C25, C26, C28, C31, C32, C35, C36: 0.1uF; C0805
C10, C29: 1uF; C0805
C11, C15, C30, C34: 0.022uF; C0805
C19, C38: RVT1E331M0810; CAP-SMD_BD8.0-L8.3-W8.3-LS9.3-FD-1
D1, D7: SS54_C22452; SMA_L4.4-W2.8-LS5.4-R-RD
D2, D4, D5, D6, D8, D10, D11, D12: SK6812; LED_SK6812_PLCC4_5.0x5.0mm_P3.2mm
D3, D9: LED; LED0805-RD
H1, H2, H3, H4, H5, H6: MountingHole; MountingHole_3.2mm_M3_Pad_Via
J1, J7: Barrel_Jack; DC-IN-TH_DC-005-A200
J2, J8: Conn_01x02; CONN-TH_P5.00_KF301-5.0-2P
J3, J4, J9, J10: Conn_02x03_Odd_Even; HDR-SMD_6P-P2.54-V
J5, J6, J11, J12: Conn_01x02_Pin; CONN-TH_P5.00_KF301-5.0-2P
L1, L2: CYA1040-33UH; IND-SMD_L11.6-W10.1
P1, P2: USB_C_Plug; USB-C_SMD-TYPE-C-31-M-12
R1, R2, R5, R6, R8, R9, R10, R11, R12, R15, R16, R18, R19, R20: 10k; R0805
R3, R4, R13, R14: 5.1k; R0805
R7, R17: 200; R0805
SW1, SW2, SW4, SW5: SW_Push; SW-SMD_L3.9-W3.0-P4.45
SW3, SW6: SW_SPDT; SW-SMD_MST-12D18G4-SPDT-SLIDE-SWITCH
U1, U6: ESP32-C3-MINI-1
U2, U7: LM2596SX-5.0/NOPB; TO-263-5_L10.2-W8.9-P1.70-TL
U3, U8: AMS1117-3.3; SOT-223-3_TabPin2
U4, U5, U9, U10: DRV8876PWPR; HTSSOP-16_L5.0-W4.4-P0.65-LS6.4-BL-EP

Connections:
+BATT: J1.1, J2.1, J7.1, J8.1, SW3.3 (C), SW6.3 (C)
BLDC_PWM: J3.2, J9.2, U1.6 (GPIO3/ADC1_CH3), U6.6 (GPIO3/ADC1_CH3)
BUZZER_DATA: BUZZER1.1 (+), BUZZER2.1 (+), U1.13 (GPIO1/ADC1_CH1/XTAL_32K_N), U6.13 (GPIO1/ADC1_CH1/XTAL_32K_N)
CHIP_PU: C7.1, C10.1, C26.1, C29.1, R1.2, R2.2, R6.2, R11.2, R12.2, R16.2, SW2.1, SW5.1, U1.8 (EN/CHIP_PU), U6.8 (EN/CHIP_PU)
D+: P1.A6 (D+), P2.A6 (D+), U1.27 (GPIO19/USB_D+), U6.27 (GPIO19/USB_D+)
D-: P1.A7 (D-), P2.A7 (D-), U1.26 (GPIO18/USB_D-), U6.26 (GPIO18/USB_D-)
ESP_3V3: C5.1, C8.2, C9.2, C24.1, C27.2, C28.2, R1.1, R2.1, R5.1, R6.1, R7.1, R8.1, R9.2, R10.2, R11.1, R12.1, R15.1, R16.1, R17.1, R18.1, R19.2, R20.2, U1.3 (3V3), U3.2 (VO), U4.5 (VREF), U5.5 (VREF), U6.3 (3V3), U8.2 (VO), U9.5 (VREF), U10.5 (VREF)
GND: BUZZER1.2, BUZZER2.2, C1.2, C2.1, C3.2, C4.2, C5.2, C6.2, C7.2, C8.1, C9.1, C10.2, C13.1, C14.1, C17.1, C18.1, C19.2, C20.2, C21.1, C22.2, C23.2, C24.2, C25.2, C26.2, C27.1, C28.1, C29.2, C32.1, C33.1, C36.1, C37.1, C38.2, D1.1 (A), D2.1 (VSS), D3.1 (K), D4.1 (VSS), D5.1 (VSS), D6.1 (VSS), D7.1 (A), D8.1 (VSS), D9.1 (K), D10.1 (VSS), D11.1 (VSS), D12.1 (VSS), J1.2, J1.MP (MountPin), J2.2, J3.5, J3.6, J4.2, J4.4, J4.6, J7.2, J7.MP (MountPin), J8.2, J9.5, J9.6, J10.2, J10.4, J10.6, P1.A1 (GND), P1.A12 (GND), P1.B1 (GND), P1.B12 (GND), P1.S1 (SHIELD), P2.A1 (GND), P2.A12 (GND), P2.B1 (GND), P2.B12 (GND), P2.S1 (SHIELD), R3.1, R4.2, R13.1, R14.2, SW1.2, SW2.2, SW4.2, SW5.2, U1.1 (GND), U1.2 (GND), U1.11 (GND), U1.14 (GND), U1.36 (GND), U1.37 (GND), U1.38 (GND), U1.39 (GND), U1.40 (GND), U1.41 (GND), U1.42 (GND), U1.43 (GND), U1.44 (GND), U1.45 (GND), U1.46 (GND), U1.47 (GND), U1.48 (GND), U1.49 (GND), U1.50 (GND), U1.51 (GND), U1.52 (GND), U1.53 (GND), U2.3 (GND), U2.5 (~ON/OFF), U2.6 (GND), U3.1 (GND), U4.6 (IPROPI), U4.9 (PGND), U4.15 (GND), U4.16 (PMODE), U4.17 (EP), U5.6 (IPROPI), U5.9 (PGND), U5.15 (GND), U5.16 (PMODE), U5.17 (EP), U6.1 (GND), U6.2 (GND), U6.11 (GND), U6.14 (GND), U6.36 (GND), U6.37 (GND), U6.38 (GND), U6.39 (GND), U6.40 (GND), U6.41 (GND), U6.42 (GND), U6.43 (GND), U6.44 (GND), U6.45 (GND), U6.46 (GND), U6.47 (GND), U6.48 (GND), U6.49 (GND), U6.50 (GND), U6.51 (GND), U6.52 (GND), U6.53 (GND), U7.3 (GND), U7.5 (~ON/OFF), U7.6 (GND), U8.1 (GND), U9.6 (IPROPI), U9.9 (PGND), U9.15 (GND), U9.16 (PMODE), U9.17 (EP), U10.6 (IPROPI), U10.9 (PGND), U10.15 (GND), U10.16 (PMODE), U10.17 (EP)
GPIO 8: R8.2, R18.2, U1.22 (GPIO8), U6.22 (GPIO8)
GPIO 9: C6.1, C25.1, R5.2, R15.2, SW1.1, SW4.1, U1.23 (GPIO9), U6.23 (GPIO9)
GPIO 10: J4.5, J10.5, U1.16 (GPIO10), U6.16 (GPIO10)
GPIO 20: J4.3, J10.3, U1.30 (GPIO20/U0RXD), U6.30 (GPIO20/U0RXD)
GPIO 21: J4.1, J10.1, U1.31 (GPIO21/U0TXD), U6.31 (GPIO21/U0TXD)
LED_DATA: D2.2 (DIN), D8.2 (DIN), U1.12 (GPIO0/ADC1_CH0/XTAL_32K_P), U6.12 (GPIO0/ADC1_CH0/XTAL_32K_P)
M1+: J5.1, J11.1, U4.8 (OUT1), U9.8 (OUT1)
M1-: J5.2, J11.2, U4.10 (OUT2), U9.10 (OUT2)
M1_IN1: U1.18 (GPIO4/ADC1_CH4), U4.1 (EN/IN1), U6.18 (GPIO4/ADC1_CH4), U9.1 (EN/IN1)
M1_IN2: U1.19 (GPIO5/ADC2_CH0), U4.2 (PH/IN2), U6.19 (GPIO5/ADC2_CH0), U9.2 (PH/IN2)
M2+: J6.1, J12.1, U5.8 (OUT1), U10.8 (OUT1)
M2-: J6.2, J12.2, U5.10 (OUT2), U10.10 (OUT2)
M2_IN1: U1.20 (GPIO6), U5.1 (EN/IN1), U6.20 (GPIO6), U10.1 (EN/IN1)
M2_IN2: U1.21 (GPIO7), U5.2 (PH/IN2), U6.21 (GPIO7), U10.2 (PH/IN2)
unnamed: D1.2 (K), D7.2 (K), L1.1, L2.1, U2.2 (OUTPUT), U7.2 (OUTPUT)
unnamed: D2.4 (DOUT), D4.2 (DIN), D8.4 (DOUT), D10.2 (DIN)
unnamed: D3.2 (A), D9.2 (A), R7.2, R17.2
unnamed: D4.4 (DOUT), D5.2 (DIN), D10.4 (DOUT), D11.2 (DIN)
unnamed: D5.4 (DOUT), D6.2 (DIN), D11.4 (DOUT), D12.2 (DIN)
unnamed: P1.A5 (CC), P2.A5 (CC), R4.1, R14.1
unnamed: P1.B5 (VCONN), P2.B5 (VCONN), R3.2, R13.2
unnamed: C11.1, C30.1, U4.13 (CPH), U9.13 (CPH)
unnamed: C11.2, C30.2, U4.14 (CPL), U9.14 (CPL)
unnamed: C12.2, C31.2, U4.12 (VCP), U9.12 (VCP)
unnamed: R9.1, R19.1, U4.3 (nSLEEP), U9.3 (nSLEEP)
unnamed: C15.1, C34.1, U5.13 (CPH), U10.13 (CPH)
unnamed: C15.2, C34.2, U5.14 (CPL), U10.14 (CPL)
unnamed: C16.2, C35.2, U5.12 (VCP), U10.12 (VCP)
unnamed: R10.1, R20.1, U5.3 (nSLEEP), U10.3 (nSLEEP)
REG_BATT+: C1.1, C2.2, C12.1, C13.2, C14.2, C16.1, C17.2, C18.2, C20.1, C21.2, C31.1, C32.2, C33.2, C35.1, C36.2, C37.2, SW3.2 (B), SW6.2 (B), U2.1 (VIN), U4.11 (VM), U5.11 (VM), U7.1 (VIN), U9.11 (VM), U10.11 (VM)
SERVO_PWM: J3.1, J9.1, U1.5 (GPIO2/ADC1_CH2), U6.5 (GPIO2/ADC1_CH2)
VCC_5V: C3.1, C4.1, C19.1, C22.1, C23.1, C38.1, D2.3 (VDD), D4.3 (VDD), D5.3 (VDD), D6.3 (VDD), D8.3 (VDD), D10.3 (VDD), D11.3 (VDD), D12.3 (VDD), J3.3, J3.4, J9.3, J9.4, L1.2, L2.2, P1.A4 (VBUS), P1.A9 (VBUS), P1.B4 (VBUS), P1.B9 (VBUS), P2.A4 (VBUS), P2.A9 (VBUS), P2.B4 (VBUS), P2.B9 (VBUS), U2.4 (FB), U3.3 (VI), U7.4 (FB), U8.3 (VI)

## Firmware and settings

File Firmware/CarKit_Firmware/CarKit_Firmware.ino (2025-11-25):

/*
 * CarKit ESP32-C3-MINI firmware
 * -----------------------------------------
 * - Bluetooth gamepad (Xbox-compatible) using Bluepad32
 * - DRV8876 (U4 = steering DC, U5 = drive DC)
 * - Optional steering servo + BLDC ESC output
 * - SD6812 / SK6812 / WS2812-compatible LEDs on GPIO0
 * - Piezo buzzer (FST-1230) tones & jingles
 * - Multiple drive modes (car & tank)
 * - Optional debug web UI to edit & persist configuration
 *
 * Pin mapping:
 *   GPIO0  -> SD6812 LED data in  (4 LEDs)
 *   GPIO21 -> broken out, unused
 *   GPIO20 -> broken out, unused
 *   GPIO10 -> broken out, unused
 *   GPIO19 -> USB
 *   GPIO18 -> USB
 *   GPIO2  -> Servo PWM breakout (steering servo)   [optional]
 *   GPIO3  -> BLDC ESC / motor controller PWM       [optional]
 *   GPIO4  -> U4 DRV8876 EN / M1_IN1 (PWM / enable)
 *   GPIO5  -> U4 DRV8876 PH / M1_IN2 (direction)
 *   GPIO6  -> U5 DRV8876 EN / M2_IN1 (PWM / enable)
 *   GPIO7  -> U5 DRV8876 PH / M2_IN2 (direction)
 *
 *   Buzzer FST-1230 -> see BUZZER_PIN below
 *
 * LED roles (index in chain, LED 0 = first after MCU):
 *   LED 0: User indicator #1 (drive/throttle)
 *   LED 1: User indicator #2 (steering)
 *   LED 2: MODE LED (drive mode)
 *   LED 3: STATUS LED (BT connection / pairing)
 */

// ==============================
//  USER-CONFIGURABLE CONSTANTS
// ==============================

#include <stdint.h>

// ---- Pin configuration ----
const int LED_PIN          = 0;   // SD6812 / SK6812 / "NeoPixel" chain data
const int BUZZER_PIN       = 1;

const int SERVO_PIN        = 2;   // Steering servo PWM breakout
const int BLDC_ESC_PIN     = 3;   // BLDC ESC PWM breakout

const int U4_EN_PIN        = 4;   // DRV8876 U4 EN / M1_IN1 (PWM / enable)
const int U4_PH_PIN        = 5;   // DRV8876 U4 PH / M1_IN2 (direction)
const int U5_EN_PIN        = 6;   // DRV8876 U5 EN / M2_IN1 (PWM / enable)
const int U5_PH_PIN        = 7;   // DRV8876 U5 PH / M2_IN2 (direction)

// ---- LEDC PWM channels ----
// (Channels are NOT pins – each channel can be attached to one pin.)
const int BUZZER_PWM_CHANNEL = 0;
const int SERVO_PWM_CHANNEL  = 1;
const int BLDC_PWM_CHANNEL   = 2;
const int U4_PWM_CHANNEL     = 3;
const int U5_PWM_CHANNEL     = 4;

// ---- Feature toggles (defaults) ----
const bool DEFAULT_REVERSE_STEERING_DC  = false;  // reverse U4 direction
const bool DEFAULT_REVERSE_DRIVE_DC     = false;  // reverse U5 direction

const bool DEFAULT_ENABLE_BLDC_OUTPUT   = false;  // ESC on GPIO3
const bool DEFAULT_ENABLE_SERVO_OUTPUT  = true;   // steering servo on GPIO2

// Tank mode: which DRV8876 is LEFT side?
// true  -> U4 = left track, U5 = right track
// false -> U5 = left track, U4 = right track
const bool DEFAULT_TANK_LEFT_IS_U4      = true;

// ---- OLD-SCHOOL ENUMS (Arduino-friendly) ----
enum HornButton {
  HORN_BTN_A = 0,
  HORN_BTN_B,
  HORN_BTN_X,
  HORN_BTN_Y,
};

const HornButton DEFAULT_HORN_BUTTON = HORN_BTN_A;

enum DriveMode {
  DRIVE_MODE_CAR  = 0,  // triggers = F/R, left stick X = steering
  DRIVE_MODE_TANK = 1,  // left & right sticks Y = tracks
};

const DriveMode DEFAULT_DRIVE_MODE = DRIVE_MODE_CAR;

// Button used to toggle drive mode at runtime (Y by default)
const HornButton DRIVE_MODE_TOGGLE_BUTTON = HORN_BTN_Y;

// ---- Servo parameters ----
// These are in microseconds and assume standard hobby servo.
const int DEFAULT_SERVO_CENTER_US  = 1500; // "0 position" trim
const int DEFAULT_SERVO_MIN_US     = 1000; // mechanical limit (left)
const int DEFAULT_SERVO_MAX_US     = 2000; // mechanical limit (right);

// ---- LED behaviour ----
const uint8_t LED_GLOBAL_BRIGHTNESS = 64;  // 0..255

// ---- Input shaping ----
const int   GAMEPAD_AXIS_MAX      = 512;    // Bluepad32 approx -512..+512
const int   GAMEPAD_TRIGGER_MAX   = 1023;   // Bluepad32 approx 0..1023
const int   AXIS_DEADZONE         = 40;     // stick deadzone
const unsigned long DRIVE_IDLE_TIMEOUT_MS = 500; // stop motors if no input

// ---- Motor PWM ----
const int MOTOR_PWM_FREQ      = 20000; // 20 kHz, above audible
const int MOTOR_PWM_RES_BITS  = 10;    // 0..1023
const int MOTOR_PWM_MAX       = (1 << MOTOR_PWM_RES_BITS) - 1;

// ---- Buzzer / jingle settings ----
const int   BUZZER_BASE_FREQ_HZ   = 4000;  // FST-1230 nominal freq
const int   BUZZER_VOLUME_DUTY    = MOTOR_PWM_MAX / 2; // ~50% duty

// ---- Servo / ESC PWM ----
const int   SERVO_PWM_FREQ        = 50;    // 50 Hz for servo/ESC
const int   SERVO_PWM_RES_BITS    = 12;    // 4096 steps in 20ms (~4.9us)
const int   SERVO_PWM_MAX         = (1 << SERVO_PWM_RES_BITS) - 1;

// ---- Debug web UI (compile-time switch) ----
#define ENABLE_DEBUG_WEBUI 1

#if ENABLE_DEBUG_WEBUI
// SoftAP credentials
const char* DEBUG_AP_SSID     = "CarKit-Debug";
const char* DEBUG_AP_PASSWORD = "carkit123";  // change if you want
#endif

// NVS namespace
const char* PREFS_NAMESPACE = "carkit";

// ==============================
//   INCLUDES
// ==============================

#include <Arduino.h>
#include <Bluepad32.h>        // Gamepad support
#include <Preferences.h>      // Persistent config (NVS)
#include <Adafruit_NeoPixel.h>

#if ENABLE_DEBUG_WEBUI
#include <WiFi.h>
#include <WebServer.h>
#endif

// ==============================
//   LED STRIP SETUP
// ==============================

const uint8_t NUM_LEDS = 4;
Adafruit_NeoPixel pixels(NUM_LEDS, LED_PIN, NEO_GRB + NEO_KHZ800);

// LED indices
const uint8_t LED_USER1 = 0;
const uint8_t LED_USER2 = 1;
const uint8_t LED_MODE  = 2;
const uint8_t LED_STAT  = 3;

// ==============================
//   CONFIG STRUCT
// ==============================

struct Config {
  bool       reverseSteeringDC;
  bool       reverseDriveDC;
  bool       enableBLDC;
  bool       enableServo;
  bool       tankLeftIsU4;
  int        servoCenterUs;
  HornButton hornButton;
  DriveMode  defaultDriveMode;
};

Config cfg;
Preferences prefs;

// ==============================
//   BLUEPAD32 / GAMEPAD
// ==============================

ControllerPtr controllers[BP32_MAX_GAMEPADS];
ControllerPtr primaryGamepad = nullptr;

bool         controllerConnected   = false;
DriveMode    currentDriveMode      = DEFAULT_DRIVE_MODE;
unsigned long lastInputMs          = 0;
bool         lastHornPressed       = false;
bool         lastModeTogglePressed = false;

// Normalized commands from -1.0 .. +1.0
float cmdDrive    = 0.0f;  // forward/reverse (car mode)
float cmdSteer    = 0.0f;  // steering [-1..1] (car mode)
float cmdTankL    = 0.0f;  // tank left
float cmdTankR    = 0.0f;  // tank right

// ==============================
//   PWM / MOTOR HELPERS
// ==============================

int dutyFromNormalized(float x) {
  x = constrain(x, -1.0f, 1.0f);
  float mag = fabs(x);
  int duty = (int)(mag * MOTOR_PWM_MAX);
  if (duty < 0) duty = 0;
  if (duty > MOTOR_PWM_MAX) duty = MOTOR_PWM_MAX;
  return duty;
}

// Drive a DRV8876 in PH/EN mode (sign-magnitude)
void setDrv8876(float normalized, int pwmChannel, int phPin, bool reverse) {
  normalized = constrain(normalized, -1.0f, 1.0f);

  if (fabs(normalized) < 0.02f) {
    // Brake low: EN=0
    ledcWrite(pwmChannel, 0);
    digitalWrite(phPin, LOW);
    return;
  }

  bool dirForward = (normalized > 0.0f);
  if (reverse)
    dirForward = !dirForward;

  int duty = dutyFromNormalized(normalized);
  digitalWrite(phPin, dirForward ? HIGH : LOW);
  ledcWrite(pwmChannel, duty);
}

// Servo pulse (50Hz via LEDC)
int servoUsToDuty(int us) {
  const float periodUs = 1000000.0f / SERVO_PWM_FREQ; // ~20000us
  float dutyCycle = (float)us / periodUs;             // 0..1
  int duty = (int)(dutyCycle * SERVO_PWM_MAX);
  if (duty < 0) duty = 0;
  if (duty > SERVO_PWM_MAX) duty = SERVO_PWM_MAX;
  return duty;
}

void setSteeringServo(float normalized) {
  if (!cfg.enableServo)
    return;

  normalized = constrain(normalized, -1.0f, 1.0f);

  int rangeLeft  = cfg.servoCenterUs - DEFAULT_SERVO_MIN_US;
  int rangeRight = DEFAULT_SERVO_MAX_US - cfg.servoCenterUs;

  int us;
  if (normalized < 0.0f) {
    us = cfg.servoCenterUs + (int)(normalized * rangeLeft);
  } else {
    us = cfg.servoCenterUs + (int)(normalized * rangeRight);
  }

  us = constrain(us, DEFAULT_SERVO_MIN_US, DEFAULT_SERVO_MAX_US);
  int duty = servoUsToDuty(us);
  ledcWrite(SERVO_PWM_CHANNEL, duty);
}

// BLDC ESC (servo-like signal for throttle)
void setBLDC(float normalized) {
  if (!cfg.enableBLDC)
    return;

  normalized = constrain(normalized, -1.0f, 1.0f);

  int us = 1500 + (int)(normalized * 500); // -1..1 => 1000..2000
  us = constrain(us, 1000, 2000);

  int duty = servoUsToDuty(us);
  ledcWrite(BLDC_PWM_CHANNEL, duty);
}

// ==============================
//   BUZZER / JINGLES
// ==============================

bool buzzerActive = false;

void buzzerInit() {
  ledcSetup(BUZZER_PWM_CHANNEL, BUZZER_BASE_FREQ_HZ, MOTOR_PWM_RES_BITS);
  ledcAttachPin(BUZZER_PIN, BUZZER_PWM_CHANNEL);
  ledcWrite(BUZZER_PWM_CHANNEL, 0);
}

void buzzerTone(int freqHz, int durationMs, int volumeDuty = BUZZER_VOLUME_DUTY) {
  if (freqHz <= 0 || durationMs <= 0) return;
  ledcSetup(BUZZER_PWM_CHANNEL, freqHz, MOTOR_PWM_RES_BITS);
  ledcWrite(BUZZER_PWM_CHANNEL, volumeDuty);
  buzzerActive = true;
  delay(durationMs);
  ledcWrite(BUZZER_PWM_CHANNEL, 0);
  buzzerActive = false;
}

void jinglePowerOn() {
  // Simple ascending three-note chime
  buzzerTone(2000, 80);
  delay(60);
  buzzerTone(2600, 80);
  delay(60);
  buzzerTone(3200, 120);
}

void jingleConnected() {
  // Short "connected" chirp
  buzzerTone(2800, 70);
  delay(40);
  buzzerTone(4000, 90);
}

// Horn while button held
void updateHorn(bool pressed) {
  if (pressed && !lastHornPressed) {
    // Start horn tone (continuous)
    ledcSetup(BUZZER_PWM_CHANNEL, BUZZER_BASE_FREQ_HZ, MOTOR_PWM_RES_BITS);
    ledcWrite(BUZZER_PWM_CHANNEL, BUZZER_VOLUME_DUTY);
    buzzerActive = true;
  } else if (!pressed && lastHornPressed) {
    // Stop horn
    ledcWrite(BUZZER_PWM_CHANNEL, 0);
    buzzerActive = false;
  }
  lastHornPressed = pressed;
}

// ==============================
//   LED ANIMATIONS
// ==============================

uint32_t color(uint8_t r, uint8_t g, uint8_t b) {
  return pixels.Color(r, g, b);
}

void ledsInit() {
  pixels.begin();
  pixels.setBrightness(LED_GLOBAL_BRIGHTNESS);
  pixels.clear();
  pixels.show();
}

// Simple power-on "wipe"
void ledsBootAnimation() {
  pixels.clear();
  for (int i = 0; i < NUM_LEDS; ++i) {
    pixels.setPixelColor(i, color(0, 0, 20 + i * 10));
    pixels.show();
    delay(80);
  }
  delay(150);
  pixels.clear();
  pixels.show();
}

void ledsSetStatusPairing() {
  // breathing blue on STATUS LED
  static uint16_t phase = 0;
  phase = (phase + 3) & 0x1FF;  // 0..511
  uint8_t b = (phase < 256) ? phase : (511 - phase);
  pixels.setPixelColor(LED_STAT, color(0, 0, b));
}

void ledsSetStatusConnected() {
  // solid green
  pixels.setPixelColor(LED_STAT, color(0, 40, 0));
}

void ledsSetMode() {
  if (currentDriveMode == DRIVE_MODE_CAR) {
    // cyan
    pixels.setPixelColor(LED_MODE, color(0, 40, 40));
  } else {
    // amber
    pixels.setPixelColor(LED_MODE, color(40, 20, 0));
  }
}

// User LEDs: visualize drive & steering
void ledsSetUserIndicators() {
  // LED_USER1 = throttle magnitude (green forward, red reverse)
  float d = constrain(cmdDrive, -1.0f, 1.0f);
  uint8_t mag = (uint8_t)(fabs(d) * 80);
  uint8_t r = (d < 0) ? mag : 0;
  uint8_t g = (d > 0) ? mag : 0;
  pixels.setPixelColor(LED_USER1, color(r, g, 0));

  // LED_USER2 = steering (blue left, magenta right)
  float s = constrain(cmdSteer, -1.0f, 1.0f);
  uint8_t m = (uint8_t)(fabs(s) * 80);
  uint8_t b = (s < 0) ? m : 0;
  uint8_t mr = (s > 0) ? m : 0;
  pixels.setPixelColor(LED_USER2, color(mr, 0, b));
}

void ledsUpdate() {
  if (controllerConnected)
    ledsSetStatusConnected();
  else
    ledsSetStatusPairing();

  ledsSetMode();
  ledsSetUserIndicators();
  pixels.show();
}

// ==============================
//   CONFIG LOAD / SAVE
// ==============================

void loadConfig() {
  prefs.begin(PREFS_NAMESPACE, true);  // read-only

  cfg.reverseSteeringDC = prefs.getBool("revSteer", DEFAULT_REVERSE_STEERING_DC);
  cfg.reverseDriveDC    = prefs.getBool("revDrive",  DEFAULT_REVERSE_DRIVE_DC);
  cfg.enableBLDC        = prefs.getBool("enBLDC",    DEFAULT_ENABLE_BLDC_OUTPUT);
  cfg.enableServo       = prefs.getBool("enServo",   DEFAULT_ENABLE_SERVO_OUTPUT);
  cfg.tankLeftIsU4      = prefs.getBool("tankL4",    DEFAULT_TANK_LEFT_IS_U4);
  cfg.servoCenterUs     = prefs.getInt ("servoCtr",  DEFAULT_SERVO_CENTER_US);
  cfg.hornButton        = (HornButton)prefs.getUChar("hornBtn", (uint8_t)DEFAULT_HORN_BUTTON);
  cfg.defaultDriveMode  = (DriveMode)prefs.getUChar("drvMode", (uint8_t)DEFAULT_DRIVE_MODE);

  prefs.end();

  currentDriveMode = cfg.defaultDriveMode;
}

void saveConfig() {
  prefs.begin(PREFS_NAMESPACE, false);

  prefs.putBool ("revSteer", cfg.reverseSteeringDC);
  prefs.putBool ("revDrive", cfg.reverseDriveDC);
  prefs.putBool ("enBLDC",   cfg.enableBLDC);
  prefs.putBool ("enServo",  cfg.enableServo);
  prefs.putBool ("tankL4",   cfg.tankLeftIsU4);
  prefs.putInt  ("servoCtr", cfg.servoCenterUs);
  prefs.putUChar("hornBtn",  (uint8_t)cfg.hornButton);
  prefs.putUChar("drvMode",  (uint8_t)currentDriveMode);

  prefs.end();
}

// ==============================
//   DEBUG WEB UI (optional)
// ==============================

#if ENABLE_DEBUG_WEBUI
WebServer server(80);

String htmlBool(bool v) { return v ? "checked" : ""; }

String htmlSelectHorn(HornButton b) {
  String s;
  s += "<select name='hornBtn'>";
  s += "<option value='0'"; if (b == HORN_BTN_A) s += " selected"; s += ">A</option>";
  s += "<option value='1'"; if (b == HORN_BTN_B) s += " selected"; s += ">B</option>";
  s += "<option value='2'"; if (b == HORN_BTN_X) s += " selected"; s += ">X</option>";
  s += "<option value='3'"; if (b == HORN_BTN_Y) s += " selected"; s += ">Y</option>";
  s += "</select>";
  return s;
}

String htmlSelectDriveMode(DriveMode m) {
  String s;
  s += "<select name='drvMode'>";
  s += "<option value='0'"; if (m == DRIVE_MODE_CAR)  s += " selected"; s += ">Car (triggers + steer)</option>";
  s += "<option value='1'"; if (m == DRIVE_MODE_TANK) s += " selected"; s += ">Tank (L/R sticks)</option>";
  s += "</select>";
  return s;
}

void handleRoot() {
  String html = R"(
<!DOCTYPE html>
<html>
<head>
<meta charset="utf-8"/>
<title>CarKit Debug Config</title>
<style>
 body { font-family: sans-serif; max-width: 600px; margin: 2em auto; }
 h1 { font-size: 1.4em; }
 label { display:block; margin: 0.3em 0; }
 fieldset { margin-bottom: 1em; }
</style>
</head>
<body>
<h1>CarKit ESP32-C3 Config</h1>
<form method="POST" action="/save">
<fieldset><legend>Motors</legend>
<label><input type="checkbox" name="revSteer" VALUE="1" %REVSTEER%> Reverse steering DC (U4)</label>
<label><input type="checkbox" name="revDrive" VALUE="1" %REVDIRVE%> Reverse drive DC (U5)</label>
<label><input type="checkbox" name="tankL4"  VALUE="1" %TANKL4%> Tank: U4 is LEFT (unchecked = U5 left)</label>
</fieldset>

<fieldset><legend>Outputs</legend>
<label><input type="checkbox" name="enServo" VALUE="1" %ENSERVO%> Enable steering servo (GPIO2)</label>
<label><input type="checkbox" name="enBLDC"  VALUE="1" %ENBLDC%> Enable BLDC / ESC output (GPIO3)</label>
<label>Servo center (µs): <input type="number" name="servoCtr" value="%SERVOCTR%" min="1000" max="2000"/></label>
</fieldset>

<fieldset><legend>Controls</legend>
<label>Horn button: %HORNBUTTON%</label>
<label>Default drive mode: %DRVMODE%</label>
</fieldset>

<button type="submit">Save</button>
</form>

<p>Current status: %STATUS%</p>
</body>
</html>
)";

  html.replace("%REVSTEER%", cfg.reverseSteeringDC ? "checked" : "");
  html.replace("%REVDIRVE%", cfg.reverseDriveDC    ? "checked" : "");
  html.replace("%TANKL4%",   cfg.tankLeftIsU4      ? "checked" : "");
  html.replace("%ENSERVO%",  cfg.enableServo       ? "checked" : "");
  html.replace("%ENBLDC%",   cfg.enableBLDC        ? "checked" : "");
  html.replace("%SERVOCTR%", String(cfg.servoCenterUs));

  html.replace("%HORNBUTTON%", htmlSelectHorn(cfg.hornButton));
  html.replace("%DRVMODE%",    htmlSelectDriveMode(currentDriveMode));
  html.replace("%STATUS%",     controllerConnected ? "Controller connected" : "Waiting for controller...");

  server.send(200, "text/html", html);
}

void handleSave() {
  cfg.reverseSteeringDC = server.hasArg("revSteer");
  cfg.reverseDriveDC    = server.hasArg("revDrive");
  cfg.tankLeftIsU4      = server.hasArg("tankL4");
  cfg.enableServo       = server.hasArg("enServo");
  cfg.enableBLDC        = server.hasArg("enBLDC");

  if (server.hasArg("servoCtr")) {
    cfg.servoCenterUs = server.arg("servoCtr").toInt();
    cfg.servoCenterUs = constrain(cfg.servoCenterUs, 1000, 2000);
  }

  if (server.hasArg("hornBtn")) {
    cfg.hornButton = (HornButton)server.arg("hornBtn").toInt();
  }
  if (server.hasArg("drvMode")) {
    currentDriveMode = (DriveMode)server.arg("drvMode").toInt();
  }

  saveConfig();
  server.sendHeader("Location", "/");
  server.send(303);
}

void startDebugWeb() {
  WiFi.mode(WIFI_AP);
  WiFi.softAP(DEBUG_AP_SSID, DEBUG_AP_PASSWORD);
  IPAddress ip = WiFi.softAPIP();
  Serial.print("Debug AP up at http://");
  Serial.println(ip);

  server.on("/", HTTP_GET, handleRoot);
  server.on("/save", HTTP_POST, handleSave);
  server.begin();
}
#endif  // ENABLE_DEBUG_WEBUI

// ==============================
//   BLUEPAD32 CALLBACKS & LOGIC
// ==============================

void onConnectedController(ControllerPtr ctl) {
  Serial.println("Controller connected");
  for (int i = 0; i < BP32_MAX_GAMEPADS; ++i) {
    if (controllers[i] == nullptr) {
      controllers[i] = ctl;
      break;
    }
  }
  primaryGamepad      = ctl;
  controllerConnected = true;
  lastInputMs         = millis();
  jingleConnected();
}

void onDisconnectedController(ControllerPtr ctl) {
  Serial.println("Controller disconnected");
  for (int i = 0; i < BP32_MAX_GAMEPADS; ++i) {
    if (controllers[i] == ctl) {
      controllers[i] = nullptr;
    }
  }
  primaryGamepad      = nullptr;
  controllerConnected = false;
  cmdDrive = cmdSteer = cmdTankL = cmdTankR = 0.0f;
}

bool isButtonPressed(ControllerPtr ctl, HornButton b) {
  switch (b) {
    case HORN_BTN_A: return ctl->a();
    case HORN_BTN_B: return ctl->b();
    case HORN_BTN_X: return ctl->x();
    case HORN_BTN_Y: return ctl->y();
    default:         return false;
  }
}

float normalizeAxis(int v, int deadzone) {
  if (abs(v) < deadzone) return 0.0f;
  float n = (float)v / (float)GAMEPAD_AXIS_MAX;  // approx -1..1
  n = constrain(n, -1.0f, 1.0f);
  return n;
}

float normalizeTrigger(int v) {
  if (v <= 0) return 0.0f;
  if (v >= GAMEPAD_TRIGGER_MAX) return 1.0f;
  return (float)v / (float)GAMEPAD_TRIGGER_MAX;
}

void processGamepad(ControllerPtr ctl) {
  if (!ctl || !ctl->isConnected()) return;

  lastInputMs = millis();

  // Read inputs
  int lx = ctl->axisX();         // left stick X
  int ly = ctl->axisY();         // left stick Y
  int ry = ctl->axisRY();        // right stick Y
  int tR = ctl->throttle();      // Right trigger (forward)
  int tL = ctl->brake();         // Left trigger (reverse)

  float fwd = normalizeTrigger(tR);
  float rev = normalizeTrigger(tL);

  // Forward/reverse from triggers: forward positive, reverse negative
  cmdDrive = fwd - rev;  // -1..+1-ish

  // Left stick X for steering
  cmdSteer = normalizeAxis(lx, AXIS_DEADZONE);

  // Tank mode: left & right sticks Y
  cmdTankL = -normalizeAxis(ly, AXIS_DEADZONE);  // invert so up = forward
  cmdTankR = -normalizeAxis(ry, AXIS_DEADZONE);

  // Horn & drive mode toggle
  bool hornNow = isButtonPressed(ctl, cfg.hornButton);
  updateHorn(hornNow);

  bool toggleNow = isButtonPressed(ctl, DRIVE_MODE_TOGGLE_BUTTON);
  if (toggleNow && !lastModeTogglePressed) {
    // rising edge: toggle drive mode
    currentDriveMode = (currentDriveMode == DRIVE_MODE_CAR)
                       ? DRIVE_MODE_TANK
                       : DRIVE_MODE_CAR;
    saveConfig(); // persist last used mode as default
  }
  lastModeTogglePressed = toggleNow;
}

void applyOutputs() {
  unsigned long now = millis();
  if (now - lastInputMs > DRIVE_IDLE_TIMEOUT_MS) {
    // Safety timeout: stop everything
    cmdDrive = cmdSteer = cmdTankL = cmdTankR = 0.0f;
  }

  if (currentDriveMode == DRIVE_MODE_CAR) {
    // Use drive & steer
    setDrv8876(cmdDrive, U5_PWM_CHANNEL, U5_PH_PIN, cfg.reverseDriveDC);     // drive DC motor (U5)
    setDrv8876(cmdSteer, U4_PWM_CHANNEL, U4_PH_PIN, cfg.reverseSteeringDC);  // steering DC motor (U4)

    setSteeringServo(cmdSteer);
    setBLDC(cmdDrive);
  } else { // TANK
    float left  = cmdTankL;
    float right = cmdTankR;

    if (cfg.tankLeftIsU4) {
      setDrv8876(left,  U4_PWM_CHANNEL, U4_PH_PIN, cfg.reverseSteeringDC);
      setDrv8876(right, U5_PWM_CHANNEL, U5_PH_PIN, cfg.reverseDriveDC);
    } else {
      setDrv8876(left,  U5_PWM_CHANNEL, U5_PH_PIN, cfg.reverseDriveDC);
      setDrv8876(right, U4_PWM_CHANNEL, U4_PH_PIN, cfg.reverseSteeringDC);
    }

    // In tank mode we keep servo centered and BLDC neutral:
    setSteeringServo(0.0f);
    setBLDC(0.0f);
  }
}

void processControllers() {
  for (int i = 0; i < BP32_MAX_GAMEPADS; ++i) {
    if (controllers[i] && controllers[i]->isConnected()) {
      processGamepad(controllers[i]);
      break; // use first connected as "primary"
    }
  }
}

// ==============================
//   SETUP & LOOP
// ==============================
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
void loop() {
  bool dataUpdated = BP32.update();
  if (dataUpdated) {
    processControllers();
  }

  applyOutputs();
  ledsUpdate();

#if ENABLE_DEBUG_WEBUI
  server.handleClient();
#endif

  delay(1); // yield
}

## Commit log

2025-11-23 Schematic mostly complete
    Finished the part selection and the control section of the schematic.
    [carkit.kicad_pcb, carkit.kicad_sch]
2025-11-24 PCB routing completed
    All components updated and the PCB should be fully functional.
    [carkit PANEL.kicad_pcb, carkit.kicad_pcb, carkit.kicad_sch]
2025-11-24 Panelization Complete
    [carkit PANEL-B_Cu.gbr, carkit PANEL-B_Mask.gbr, carkit PANEL-B_Paste.gbr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]
2025-11-24 Initialize README with project details and features
    Added detailed project description, features, and usage instructions for the CarKit RC control board.
2025-11-24 Quick fix
    [BOM.csv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]
2025-11-24 Update PCB renders
    Refreshed bottom and top PCB render images.
2025-11-24 Restructure Files
    [BOM.csv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]
2025-11-25 Update BOM
    Updated BOM to use ESP32-C3-WROOM-02-H4, adjusted pricing, and clarified top-up costs.
    [BOM.csv]
2025-11-25 Add CarKit firmware
    Added initial CarKit ESP32-C3-MINI firmware which has support for BLE gamepads
    [carkit.kicad_sch]
2025-11-25 Create README.md for CarKit firmware documentation
    Add comprehensive README for CarKit firmware, detailing features, pin mapping, configuration, and build instructions.
